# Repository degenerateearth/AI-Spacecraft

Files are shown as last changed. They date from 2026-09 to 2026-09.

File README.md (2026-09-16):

# DEGEN-1
## 1U CubeSat preliminary engineering design — Revision A

Issued 14 September 2026. Status: **AUDITABLE PRELIMINARY DESIGN / NOT RELEASED FOR FABRICATION OR FLIGHT**.

The current goal is an [education-grade, theoretically buildable design](review/Theoretical_Buildability_Standard.md).
It requires exact verifiable parts, released custom designs, reconciled interfaces
and reproducible engineering analyses. Purchasing and physical testing are later
validation stages and are not required to complete the theoretical design.

## First engineering step

The controlling first engineering gate is [Phase 1 component evidence
closure](review/First_Engineering_Gate.md). DEGENERATE-1 must establish an exact,
commercially obtainable or explicitly custom-designed component for every
required function before further simulation, higher-fidelity CAD, procurement or
performance claims can control the project. Existing calculations and CAD remain
preliminary records and do not supply missing component properties.

The [Phase 1 closure review package](Components/phase1_closure/README.md) now
supersedes the earlier 29-line operating proposal for review. Its consolidated
register contains 52 flight, ground and support records: 5 bounded component-level
SUPPORTED records, 25 genuine custom work packages and 22 explicit COTS or
configuration evidence exceptions. No flight component is newly admitted, and
no custom work package is a released design. G1 therefore remains open.

The design targets one year of opportunistic imaging and housekeeping telemetry in LEO at low build cost using commercially marketed CubeSat subsystems. The owner selected occasional recognizable Earth images, US operation and nominal 450–500 km LEO, with no arbitrary spacecraft budget ceiling. Revision A proposed a CrystalSpace CS-101 camera; the evidence audit prefers SkyFox piCAM/FM, but neither is admitted to the Phase 1 baseline. Selected-location imaging or mapping would require a revised baseline.

The original pre-gate candidate architecture used an ISISPACE 1U chassis,
ICEPS2 power, and GomSpace avionics. The [open-bus architecture
trade](engineering/12_Open_Bus_Architecture_Trade.md) now rejects that mixed
commercial set as the design-development baseline because necessary public
interfaces do not close. Degen-1 will develop a BIRDS-derived 1U architecture
with project-released custom avionics and current exact BOMs. This is an
architecture direction, not an admitted component baseline; G1 remains open.

The original [component audit](Components/README.md) covers every existing B01–B16 BOM line. The stricter [Phase 1 functional audit](Components/Phase1_Functional_Audit.md), [105-row property matrix](Components/Phase1_Component_Property_Matrix.csv) and [evidence standard](review/Phase1_Component_Evidence_Standard.md) find that **no physical component has yet passed into the Phase 1 baseline**. Named products remain candidates until public primary evidence establishes every mission-relevant property. The audit identifies SkyFox `piCAM/FM` as a better documented camera candidate, corrects NanoDock DMC-3 availability, and records Pumpkin structure/panel alternatives without promoting them. None of these findings silently changes the controlled BOM.

**Planning results:** 1.064 kg current best estimate, 1.276 kg including 20% growth; EUR46,500 base flight-hardware allowance (EUR29,350–70,100 range). These are engineering estimates, not supplier quotations. Spacecraft build, including engineering/prototype hardware, assembly and nonrecurring engineering labor, is EUR152,500 base before contingency. Testing, ground station, licensing, launch and operations are separate categories. The cost report explains inclusions and uncertainty.

The original scalar power model closes nominal energy at +18.4% with a tumble-average assumption and reported +0.124 Wh/orbit for fixed-attitude recovery. The later 11-node calculation is reclassified as **HYPOTHETICAL PARAMETRIC SENSITIVITY — NOT COMPONENT-SPECIFIC** after the [Thermal Model Incident](review/incidents/Thermal_Model_Incident.md). Its precise numerical outputs depend on unsupported thermal properties and cannot pass or fail the spacecraft or an identified component. Thermal feasibility, orbit lifetime, radiation, inhibit independence and final mechanical/interface compliance remain open. No analysis in this package demonstrates launch survival or twelve-month operation.

### Audit reading order

1. [First engineering gate](review/First_Engineering_Gate.md), [Phase 1 evidence standard](review/Phase1_Component_Evidence_Standard.md), and [functional component audit](Components/Phase1_Functional_Audit.md)
2. [Mission and architecture](engineering/01_Mission_and_Architecture.md)
3. [System budgets and analysis rationale](engineering/02_Budgets_and_Analyses.md)
4. [Interfaces and adapter specification](engineering/03_Interfaces.md)
5. [Mechanical and environmental design](engineering/04_Mechanical_Thermal_Radiation.md)
6. [Flight software and mission operations](engineering/05_Software_and_Operations.md)
7. [Assembly, integration and verification](engineering/06_Integration_and_Verification.md)
8. [Cost and procurement trade](procurement/Cost_and_Procurement.md)
9. [Open issues and review gates](review/Open_Issues.md)
10. [Imaging payload](engineering/07_Imaging_Payload.md) and [US compliance plan](engineering/08_US_Compliance.md)
11. [Launch and deployer planning baseline](engineering/09_Launch_and_Deployer_Baseline.md)
12. [Preliminary transient thermal-power analysis](engineering/11_Transient_Thermal_Power_Analysis.md)
13. [Requirements traceability](review/Requirements.md), [FMEA](review/FMEA.md), [sources](review/Source_Register.md)
14. [Known downstream dependencies](review/Known_Downstream_Dependencies.md)
15. [Phase 1 consolidated component register](Components/phase1_closure/component_register.md), [alternatives](Components/phase1_closure/alternative_review.md), and [build-and-operate completeness audit](Components/phase1_closure/completeness_audit.md)
16. [Open-bus architecture trade](engineering/12_Open_Bus_Architecture_Trade.md) and [upstream revision register](review/Open_Source_Upstream_Register.md)

### Reproduction and configuration

Run `python analysis/recalculate.py` for the original scalar budgets. Run `python analysis/thermal_transient.py --self-test` for the 11-node transient thermal-power model; its canonical inputs are `analysis/thermal_inputs.json` and its CSV/JSON/SVG outputs are regenerated. Both scripts use Python's standard library. Assertions and numerical checks verify model consistency, not flight hardware. The HTML audit book is an earlier generated snapshot; the individual Markdown documents and model inputs are authoritative within this package.

The original SVG is an allocation sketch. [CAD-001 FreeCAD model](drawings/freecad/README.md) now provides editable parametric component envelopes and a STEP review export, with explicit assumptions and fit conflicts. It is not manufacturing CAD or supplier geometry. The electrical diagrams specify functional interfaces, not a released pin-to-pin harness. PCB fabrication files, vendor proprietary ICDs, supplier quotes, hardware test reports and flight software implementation remain incomplete.

All external facts carry source IDs resolved in the source register. **V** denotes vendor-stated information; **A** denotes an engineering assumption/allocation; **C** denotes a calculation; **OPEN** denotes missing evidence. Published product changes supersede older brochures. Engineering approval signatures remain blank; AI authorship is not an engineering release.

## Project purpose — added after Revision A

Read the [Project Overview](Project_Overview.md) for the AI-assisted engineering experiment and the owner's [Project Constitution v0.1](Project_Constitution.md) for its principles and success levels. The Revision A audit book remains the earlier technical snapshot; these documents do not imply a new engineering or flight-readiness release.
## Consumer-AI experiment constraint

The baseline engineering interface is a standard $20/month ChatGPT Plus subscription, including Codex/Astra where available, with free/open-source engineering tools wherever practical. Paid AI or software is not introduced silently. See [AI toolchain and boundaries](review/AI_Toolchain_and_Boundaries.md), [project status](review/Project_Status.yaml), and the separate [project cost ledger](procurement/Project_Cost_Ledger.csv).

Project gates and their required evidence are tracked in [MILESTONES.md](MILESTONES.md). GitHub updates are made at those review points.

Before planning major engineering work, consult the [Master CubeSat Readiness Checklist](review/Master_CubeSat_Readiness_Checklist.md). It audits this repository against an independent University of Hawaiʻi CubeSat development framework plus primary launch, NASA and US regulatory sources. The public-information-phase reassessment leaves the project at Constitution Level 0 with partial evidence toward Level 1. It distinguishes current work from final closure that depends on later vendor, regulator, integrator, test or expert evidence.

The [Launch and Deployer Constraint Gate](engineering/09_Launch_and_Deployer_Baseline.md) selects a standard 1U EXOpod Nova slot as a provisional mechanical reference. No launch, orbit, price, mission ICD or acceptance is selected. EXOLAUNCH and ISISPACE require written offers; ISS/NRCSD remains a lower-orbit fallback whose one-year residence is unproved.

The project is presently in a public-information development phase. Direct
contact for private or mission-specific evidence is tracked as a [known
downstream dependency](review/Known_Downstream_Dependencies.md), while public
analysis, CAD, simulation and test planning continue. This sequencing does not
waive public requirements or turn provisional inputs into release evidence.

Archived external-framework provenance and licensing are recorded in [SOURCES/README.md](SOURCES/README.md).

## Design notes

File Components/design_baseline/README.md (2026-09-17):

# Degen-1 detailed-design selection register

Revision A · 2026-09-16

This directory records exact parts and custom assemblies selected after
D1-TRD-ARCH-001. A selection here is an input to detailed design. It becomes
`SUPPORTED` under D1-CMP-STD-001 only when every property actually used by the
released design is backed by primary evidence.

Current states:

| State | Meaning |
|---|---|
| SELECTED FOR DETAILED DESIGN | Exact part/topology chosen; further interface, circuit or analysis closure is required |
| SUPPORTED | Exact selection and all controlling mission properties are evidenced for the stated use |
| CUSTOM/TO BE VERIFIED | Degen-1 design has a defined identity and verification path; release artifacts are incomplete |
| REJECTED | Evaluated and unsuitable for the baseline, with reason retained |

| ID | Item | State | Record |
|---|---|---|---|
| D1-BAT-001 | 3S2P Panasonic BK120AAHU battery assembly | SELECTED FOR DETAILED DESIGN | [Battery record](D1-BAT-001.md) |
| D1-OBC-001 | BIRDS-derived PIC/serial-flash OBC | CUSTOM/TO BE VERIFIED | [OBC record](D1-OBC-001.md) |
| D1-EPS-001 | Power, charging, rails and launch inhibits | CUSTOM/TO BE VERIFIED | [EPS record](D1-EPS-001.md) |
| D1-BPB-001 | Backplane and fixed electrical interfaces | CUSTOM/TO BE VERIFIED | [Backplane record](D1-BPB-001.md) |
| D1-CAM-001 | SkyFox Labs piCAM/FM camera and custom carrier | SELECTED FOR DETAILED DESIGN | [Camera record](D1-CAM-001.md) |
| D1-COM-001 | Ebyte E22-400M22S UHF radio and custom carrier | CUSTOM/TO BE VERIFIED | [Radio record](D1-COM-001.md) |
| D1-SOL-001 | Five custom panels with ten AZUR SPACE 81442 SCAs and five YAGEO Nexensos 32208571 Pt1000 sensors | CUSTOM/TO BE VERIFIED | [Solar-panel record](D1-SOL-001.md) |
| D1-ADCS-001 | K&J D84 magnet, two custom HyMu 80 rods and retainers | CUSTOM/TO BE VERIFIED | [Passive ADCS record](D1-ADCS-001.md) |
| D1-ANT-001 | Custom 436.5 MHz canted-turnstile and four-channel release assembly | CUSTOM/TO BE VERIFIED | [Antenna/deployment record](D1-ANT-001.md) |
| D1-STR-001 | BIRDS-4-derived custom 1U rail frame | CUSTOM/TO BE VERIFIED | [Structure record](D1-STR-001.md) |
| D1-FAB-001 | Launch inhibits, RBF and front service access | CUSTOM/TO BE VERIFIED | [Flight-access record](D1-FAB-001.md) |
| D1-HAR-001 | Flight and removable service harnesses | CUSTOM/TO BE VERIFIED | [Harness record](D1-HAR-001.md) |

This register will replace the earlier mixed-vendor component proposal only
after all required functions have equivalent detailed records and the generated
Phase 1 register is revised. Until then, the earlier register remains the formal
list of open evidence exceptions and G1 remains open.

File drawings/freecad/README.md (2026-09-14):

# Degen-1 CAD-001 — FreeCAD accommodation model

MODELED / PRELIMINARY / NOT FOR FABRICATION OR FLIGHT.

This translates the existing Revision A spacecraft into editable component
envelopes. It does not substitute a generic 1U design. Read
[TRACEABILITY.md](TRACEABILITY.md) and [FINDINGS.md](FINDINGS.md) before using it.

- `parameters.json`: canonical dimensional inputs, object names, evidence, sources and requirements.
- `build.py`: canonical generator, intersection audit, assigned BOM masses and verification routine.
- `Build_Degen1.FCMacro`: run in the installed FreeCAD GUI to regenerate and preview.
- `exports/Degen1_CAD001.FCStd`: editable native document with Spreadsheet-driven Part boxes.
- `exports/Degen1_CAD001_envelopes.step`: interoperability solids; references and unknown interfaces excluded. All solids are bounding/allocation volumes, not material.
- `exports/assembly.png`: FreeCAD view, when generated by GUI macro.
- `exports/geometry_report.json`: computed overlaps, distances, bounds and mass reconciliation.
- `exports/verification.json`: saved-file and STEP software verification.

## Reproduction

Installed tool: FreeCAD 1.1.3, revision 20260725, Python 3.11 (bundled).
No paid tools, cloud compute or external engineering service used for this CAD work.

In FreeCAD, open the macro through Macro > Macros and Execute. It resolves paths
relative to itself. It creates a new document, retaining any other open document.
Close unsaved variants deliberately yourself; do not confuse them with the saved baseline.

For repeatable command-line generation using this computer's installed FreeCAD:

```powershell
& "$env:LOCALAPPDATA\Programs\FreeCAD 1.1\bin\python.exe" "D:\Degen-1\drawings\freecad\build.py"
& "$env:LOCALAPPDATA\Programs\FreeCAD 1.1\bin\python.exe" "D:\Degen-1\drawings\freecad\build.py" --verify
```

The commands use the actual installed FreeCAD modeling kernel. The GUI macro
also saves colors, transparency and a view. Headless regeneration preserves
geometry but does not produce the same graphical presentation.

Edit the native `Parameters` spreadsheet's B column and recompute to change
dimensions/centers. All boxes have expression-driven size and location.
For durable reproducibility, propagate accepted edits back to `parameters.json`
and regenerate; generation overwrites the saved output files. STEP cannot retain
the expression graph, evidence metadata or unknown-interface records.

`References` contains hidden nominal envelope, bay and service-clearance volumes.
Toggle their visibility for inspection; they are not physical parts or masses.
`UnresolvedInterfaces` contains records without geometry so missing hardware is
visible in the tree. Turn off `SolarPanels` for an internal view.

Geometry checks enumerate every component pair, calculate Boolean intersection
volumes, report distances <=3 mm, and check containment in the project nominal
100 x 100 x 113.5 mm envelope. 3 mm is a reporting threshold, not a requirement.
No universal clearance acceptance, tolerance analysis, mounting validation,
structural simulation, thermal simulation or hardware test is implied.

Verify regenerations by comparing geometry signatures, not FCStd/STEP binary
hashes: files may contain time-dependent metadata. Verification reopens FCStd in
a fresh process, changes camera length through its spreadsheet expression,
restores it, checks all solids and reads STEP back. Expected overlaps are retained.

GitHub milestone identifiers M0-M7 are organizational checkpoints, distinct from
constitution success levels. This first CAD does not close M2/M3 or increase the
existing success-level claim.

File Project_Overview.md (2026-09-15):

# DEGENERATE-1 — Project Overview

Version 0.1 · Living document · 14 September 2026

## What this project is

DEGENERATE-1 is an experiment in how far a non-engineer can get in spacecraft engineering and development using AI as their primary tool.

The project follows a real spacecraft-development effort and documents what AI helps accomplish, what it gets wrong, what the human operator learns, and where independent expertise or physical testing becomes necessary. Its value comes from a credible, inspectable record of progress, including any limits that prevent it from reaching orbit.

AI is the main interface for research, calculations, design exploration, software and documentation. It is not an engineering authority. A convincing answer or a polished document is a proposal to examine, not proof that a spacecraft will work.

## The spacecraft mission

The practical objective is to build a small spacecraft that captures a recognizable photograph of Earth, stores it onboard, transmits it to a privately constructed ground station, and allows that station to reconstruct the image. Basic telemetry should show whether the spacecraft is healthy.

The memorable finish line is a physical printer at the ground station producing the photograph received from orbit: the constitution's **Cornfield Criterion**.

High-resolution mapping, selected-location targeting and real-time video are unnecessary for this objective. The owner has selected occasional recognizable Earth images.

## What the experiment should measure

Progress should be measured by evidence and demonstrated capability. For each meaningful milestone, record:

- What the non-engineer asked AI to help accomplish.
- What AI proposed, including its assumptions and sources.
- What calculations, source checks, independent review or tests supported or contradicted the proposal.
- What changed, why it changed, and who identified the problem.
- How much human effort, specialist assistance, money and time were required, when known.
- What the human operator can now explain or demonstrate.

These records should make it possible to distinguish AI-assisted progress from work completed by suppliers, professional engineers or test facilities. Both are useful contributions; their roles should remain visible.

This is a documented case study. One project's outcome will not establish that AI can replace aerospace engineers generally.

## What counts as success

The constitution defines separate stages: concept, supported engineering model, expert review, ground prototype, verified flight-candidate hardware, licensed launch readiness, orbital operation, image return and finally the printed photograph.

Reaching one stage does not establish the next. A useful result could also be a well-documented stopping point: for example, discovering that a required interface cannot be verified, a design lacks sufficient margin, or the cost of qualification makes the mission impractical.

Meaningful failures belong in the record. Preserve the original proposal, the problem discovered, the correction and the lesson. Correct the current design without rewriting the history of how it arrived there.

## Current starting point

The existing **Degen-1 Revision A** package is a preliminary 1U CubeSat design for opportunistic Earth imaging. It includes component candidates, calculation files, estimated costs, requirements and open issues.

It provides a concept and partial evidence toward the constitution's engineering-model stage. It does not establish a fully consistent, verified engineering model or any higher success level. No independent expert review, hardware purchase, prototype, environmental qualification, licensing approval or orbital operation has been demonstrated in the project record so far.

The initial technical baseline targets US operation in approximately 450–500 km LEO and twelve months of operation. The constitution allows a different form factor when a documented trade supports it. It also defines the minimum image-return objective separately from the original twelve-month target. This overview does not silently remove that target or change the current hardware architecture; any such change should be an explicit, traceable design decision.

## How the project should develop

The first engineering step is to close the Phase 1 component evidence gate. The
project must identify an exact documented COTS configuration or release a custom
design for every required function before additional simulation or detailed CAD
can become the controlling work product. Preliminary work already present in the
repository remains useful for discovering required properties and conflicts, but
it does not reverse this order or establish component behavior.

Prefer designs that can be understood, sourced, checked, built and tested. Use commercially available hardware where it reduces total effort and risk. Keep assumptions and missing information visible, propagate design changes through all affected budgets, and obtain appropriate specialist review before treating work as independently validated.

Explain important decisions in language the operator can understand: the decision, its purpose, the evidence, the assumptions and how it could be verified. Developing the operator's understanding is part of the experiment.

The intended public record should show both the spacecraft's development and AI's actual contribution. GitHub is the intended canonical technical record; a future website should explain the project and link to that record. No repository or publication is created by this document. Files currently remain in `D:\Degen-1`.

## Project documents

- [Project Constitution v0.1](Project_Constitution.md) — the owner's full statement of purpose and working principles, preserved as supplied.
- [Technical package README](README.md) — entry point to the existing design documents and calculations.
- [Revision A audit book](Degen-1_Audit_Book.html) — the earlier technical snapshot; it predates this overview and constitution.
- [Open issues](review/Open_Issues.md) — unresolved technical and regulatory evidence.

**North star:** a spacecraft we built photographs Earth, sends the image home, and our ground station prints it—while leaving an honest record of how far AI helped us get.
## Consumer-AI boundary

The accessibility baseline is a standard $20/month ChatGPT Plus subscription, including Codex/Astra where available, plus free and open-source engineering software wherever reasonably practical. Enterprise AI, specialist AI platforms, large API expenditures, paid cloud compute and paid engineering services are not silently added. If the consumer/free toolchain reaches a credible boundary, record the limitation, required capability and estimated cost and ask before introducing a paid tool or service.

Keep AI/tooling costs separate from spacecraft hardware, ground station, testing, licensing, launch/integration, and external human expert review. Physical testing is not AI expenditure, and professional review must be attributed to human expertise.

## Current public-information phase

The current phase deliberately uses public standards, manuals, datasheets,
research and free/open tools to mature the design as far as they credibly allow.
External requests for private or mission-specific information are deferred until
they are needed for an irreversible or expensive commitment. Those needs are
tracked as **KNOWN DOWNSTREAM DEPENDENCIES**, together with the useful analysis,
CAD, simulation and prototype work that can continue now.

This sequencing does not convert provisional public information into an
approved interface. The public EXOpod Nova manual remains the provisional
mechanical reference. A current mission ICD, as-procured component data,
regulatory determinations, physical test evidence and professional review will
still be required at their applicable release gates.

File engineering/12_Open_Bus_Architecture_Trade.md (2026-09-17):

# D1-TRD-ARCH-001 — Open-bus architecture trade

Revision A · 2026-09-16  
Evidence state: **DOCUMENTED TRADE STUDY; no hardware tested**

## Decision question

Which publicly documented architecture provides the most credible path to a
complete, auditable, education-grade 1U Earth-imaging design without depending
on private vendor interfaces?

The comparison is about the public design record. Flight heritage of a related
revision is supporting evidence, not proof that a Degen-1 derivative will work.

## Mandatory criteria

1. A 1U implementation must be physically possible.
2. Hardware must be represented by exact COTS parts or released custom designs.
3. Schematics, PCB source or a declared custom-layout task, mechanical interfaces,
   firmware and test information must be publicly reviewable.
4. The design must support command, health telemetry, image capture, storage and
   image downlink without a hidden command protocol.
5. Known radiation, power, safety or integration failures must remain visible.
6. The editable toolchain must be free/open where reasonably practical.

## Results

| Candidate | Public strengths | Controlling defects | Disposition |
|---|---|---|---|
| Existing ISISPACE/GomSpace/SkyFox mix | Current identifiable products; compact flight-oriented packaging | Several command definitions, option codes, pinouts and cross-vendor configuration details are not public; 22 evidence-incomplete selections remain in the Phase 1 register | Rejected as the design-development baseline; retained as a commercial comparison |
| BIRDS-4/BIRDS-5 1U bus | Repeated 1U educational missions; English platform ICD; structure CAD; board schematics and BOMs; firmware; antenna, battery and environmental procedures; documented energy figures; direct Earth-imaging precedent | Core OBC/EPS PCB layouts are not public; some 2018 BOM entries are obsolete or ambiguous; the exact current radio configuration and procurement route require reconciliation | **Selected reference architecture for a Degen-1 custom derivative** |
| PyCubed v05 | Complete KiCad source, fabrication data, STEP, firmware and integrated OBC/EPS/radio | The project warns of serious proton sensitivity in the ATSAMD51 used by v00–v05; example command handling includes static tokens and unrestricted evaluation/execution; solar-input topology conflicts with ordinary two-cell 1U body panels | Rejected unchanged; retained as an implementation reference |
| OreSat0 / OreSat current repositories | Coherent open card-cage architecture; 1U flight article; open C3, backplane, battery and solar designs; strong fabrication notes and test culture | Flown C3 v5 had both receiver defects; current C3 v6 is a post-flight redesign with no public board power characterization found; flown battery v3.0 is an older Eagle design while current KiCad layout is explicitly in progress | Strong reference, not a single reproducible current baseline |
| VST104-Sierra | Complete KiCad OBC, exact BOM alternatives, broad protected interfaces and STM32L496 firmware scaffold | No mission flight software; needs both 3.3 V and 5 V; no matched EPS/radio in the VST104 set; no flight or radiation-test record found | Retained as OBC fallback/reference |
| OpenLST rev 2.1 | Complete KiCad, Gerbers, exact BOM, firmware, ground tools and extensive related Planet LST flight heritage | Reference PA RFFM6403 is discontinued; STA1120A evidence/order route is incomplete; board connector selections are unfinished; a current derivative requires RF redesign and test | Retained as radio fallback/reference |
| UPSat open bus | Flown fully open satellite with EPS, OBC, communications, camera software, structures and verification history | The integrated spacecraft is 2U; 2016 parts/tooling need obsolescence review; a 1U repack would be a new mechanical and thermal design | Retained as subsystem and verification reference |

## Selected architecture direction

Degen-1 will use a **BIRDS-derived 1U mechanical and electrical architecture with
project-released custom avionics boards**. The selection is architectural, not an
authorization to copy an unavailable board layout or to treat old BOM entries as
current.

The reasons are:

- BIRDS demonstrates that the chosen stack style, passive-stability concept,
  body-mounted solar generation, low-data-rate UHF link and small camera payload
  can coexist in 1U;
- the public platform ICD, circuit schematics, firmware and verification records
  expose more of the complete spacecraft than the commercial mixed-vendor design;
- Degen-1 can recreate the missing layouts in KiCad and record every substitution,
  instead of relying on private command dictionaries; and
- the architecture already separates platform, communication, antenna, payload
  and backplane functions in a form that can be audited by students and engineers.

## Frozen functional partition

| Degen-1 item | Baseline direction | Present evidence state |
|---|---|---|
| Structure and rails | Custom D1-STR-001 derived from public BIRDS 1U drawings and checked against the provisional EXOpod Nova envelope | Selected direction; Degen-1 production drawings not released |
| Backplane and harness | Custom D1-BPB-001 using the BIRDS 50-pin stack interface as the starting pin map | Selected direction; pin-level Degen-1 ICD not released |
| OBC and nonvolatile storage | Custom D1-OBC-001 derived from the BIRDS-4 PIC/flash architecture and firmware; every obsolete/ambiguous part must be replaced before schematic release | Selected direction; layout and current BOM not released |
| Power, inhibits and distribution | Custom D1-EPS-001 derived from the BIRDS FAB/EPS safety architecture, with three independent deployment inhibits, RBF isolation, battery protection and separately switched payload/radio rails | Selected direction; schematic and current BOM not released |
| Battery | Custom D1-BAT-001 using six exact Panasonic `BK120AAHU` NiMH cells in a 3S2P topology | Exact cell and topology selected; pack drawing, analysis and verification remain open |
| Solar panels | Custom D1-SOL-001 body panels using exact AZUR `81442` SCAs, Nexperia blocking diodes and YAGEO Nexensos `32208571` Pt1000 sensors; PCB, readout and attachment remain to be released | Open detailed design |
| TT&C and image downlink | Custom D1-COM-001 carrier using exact Ebyte `E22-400M22S` / Semtech SX1268 module; public Degen-1 waveform and packet protocol | Exact module selected; carrier, waveform and link closure open |
| Antenna/deployment | Custom D1-ANT-001 derived from the documented BIRDS tape-antenna mechanism and launch-inhibit logic | Selected direction; drawings and release circuit not released |
| Camera | SkyFox Labs `piCAM/FM`, default approximately 60-degree optics, IR-cut and infinity focus | Exact payload selected; carrier, delivered connector suffix and protection release open |
| Passive attitude behavior | Permanent magnet plus hysteresis material only if exact sizing and image-probability analysis close; no active pointing is added | Open detailed design |
| Flight software | Degen-1 fork/reimplementation of the BIRDS state-machine and command concepts with authenticated command parsing, bounded buffers and no dynamic evaluation | Custom work package |
| Ground segment | SDR/packet modem, directional antenna, rotator and image reconstruction matched to the released space link | Custom integration plus exact COTS items |

## Design boundary exposed by the trade

No reviewed open design simultaneously provides a current exact BOM, complete
1U fabrication package, demonstrated 12-month radiation tolerance, camera mission,
and fully documented ground link. Degen-1 must perform real electrical, RF,
mechanical and software design work. Reusing public source reduces the amount of
new work; it does not transfer qualification or flight status.

The consumer-AI/free-toolchain experiment can credibly continue through source
reconciliation, KiCad/FreeCAD design, deterministic analysis and prototype test
planning. RF layout review, battery safety review, launch structural review,
environmental qualification and regulatory approval remain expected external or
physical-verification boundaries.

## Primary public records used

- BIRDS platform documentation: https://github.com/BIRDSOpenSource/BIRDS-GeneralDocumentation
- BIRDS-4 OBC: https://github.com/BIRDSOpenSource/BIRDS4-OBC
- BIRDS-4 communications: https://github.com/BIRDSOpenSource/BIRDS4-COM
- BIRDS-4 FAB/EPS: https://github.com/BIRDSOpenSource/BIRDS4-FAB
- BIRDS-4 CAD and procedures: https://github.com/BIRDSOpenSource/BIRDS4-CAD and https://github.com/BIRDSOpenSource/BIRDS4-ProceduresAndReports
- BIRDS-5 published parts/designs/CAD/source: https://github.com/BIRDSOpenSource
- BIRDS-RPM communication record: https://birds-rp.birds-project.com/communication/
- PyCubed hardware/software: https://github.com/pycubed and the August 2024 processor notice in its official documentation
- OreSat hardware: https://github.com/oresat/oresat-c3-hardware, https://github.com/oresat/oresat-batteries, https://github.com/oresat/oresat-solar-hardware, and https://github.com/oresat/oresat-backplane
- VST104-Sierra: https://github.com/visionspacetec/VST104-Sierra
- OpenLST: https://github.com/OpenLST/openlst and https://www.planet.com/open/openlst-hw.git
- UPSat: https://gitlab.com/librespacefoundation/upsat

Exact upstream commit identifiers used for this audit are recorded in
`review/Open_Source_Upstream_Register.md`.

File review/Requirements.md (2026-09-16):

# D1-REQ-001 — Requirements and verification traceability

Revision A. A=analysis, T=test, I=inspection. MODEL PASS is not hardware compliance. Tests resolve to D1-AIV-001; all executed work here is document/model verification only.

| ID | Requirement | Origin | Owner | Method | Evidence | Status |
|---|---|---|---|---|---|---|
| R01 | Operate for 365.25 days after separation | User | System | A/T | T07,T08,T13,T16,T17 | OPEN: life evidence |
| R02 | Return occasional recognizable Earth images; commissioning image and monthly target | User + allocation | Payload | A/T | T11,T17 | OPEN: opportunity and image test |
| R03 | Use standard 1U rail-deployer envelope; EXOpod Nova is provisional mechanical reference and final ICD governs | User/S01/S33 | Mechanical | I/T | T01 | PROVISIONAL MODEL SCREEN: nominal 100 x 100 x 113.5 mm; tolerances and fit open |
| R04 | Mass <=1330 g project target; actual manifest limit governs | Allocation/S33 | Mechanical | A/T | T02 | MODEL PASS:1276.2 g with growth versus 2.5 kg public Nova reference; hardware/manifest open |
| R05 | COM target +/-10mm in each axis | Allocation/S33 | Mechanical | T | T02 | OPEN: project target is tighter than Nova +/-20 mm guidance; credible model and measurement absent |
| R06 | Minimum-cost viable theoretical design; maximize practical use of documented COTS hardware and define every necessary custom item | User | Systems | Review | Cost model and design register | OPEN: detailed baseline and estimates |
| R07 | Nominal orbit-energy balance positive after 20% growth | Allocation | EPS | A/T | T06,T07 | MODEL PASS:+18.4%; environment inputs open |
| R08 | Recovery energy closes in worst intact-face attitude, camera off | Allocation | EPS/FSW | A/T | T06,T07,T13 | OPEN: scalar screen is assumption-dependent; hypothetical thermal study is not component evidence |
| R09 | Battery routine DOD <=20% EOL capacity; >=6000-cycle evidence | Allocation | EPS | A/T | T08 | MODEL PASS DOD only; life open |
| R10 | Never charge outside approved cell current/temperature limits | S03/project target | EPS | T | T03,T13,T15 | OPEN: public product limits are partial; exact delivered configuration, independent control and physical tests remain open |
| R11 | Three independent physical RF and release inhibits unless approved tailoring | S01/S39; mission ICD TBD | Safety | A/T | T04 | OPEN: public Nova manual does not close circuit independence or mission safety acceptance |
| R12 | No early deployment/RF; delays >=30/45min or longer ICD | S01 | Safety/FSW | T | T05 | OPEN |
| R13 | RBF/source isolation includes solar and service paths | S01/S03 | Safety | A/T | T04 | OPEN |
| R14 | Recover from OBC hang, bus fault and low battery autonomously | Allocation | FSW/EPS | T | T07,T15 | OPEN |
| R15 | No downstream overvoltage or back-powering at avionics | S03/S08/S10 | Electrical | A/T | T03 | OPEN: adapter design |
| R16 | Correct Mode 5 framing with >=3dB tested link reserve | S11/allocation | RF | A/T | T09 | MODEL PASS:6.49dB down; threshold open |
| R17 | RF band, EIRP and sites authorized before use | User | Regulatory | Review | FCC/coordination grants | OPEN |
| R18 | NOAA determination/license for full imaging capability | User/S24 | Regulatory | Review | NOAA evidence | OPEN |
| R19 | Retain 30 days health and bounded image store | Allocation | FSW | T | T11,T15 | OPEN |
| R20 | Authenticated critical commands, replay control and persistent RF stop | Allocation | FSW | T | T15,T17 | OPEN: license-compatible implementation |
| R21 | Structure survives approved launch environment | User | Mechanical | A/T | T12,T18 | OPEN: analysis and test |
| R22 | Thermal model closes charging/survival and energy simultaneously | User | Thermal | A/T | T13 | NOT STARTED: the existing calculation is hypothetical sensitivity only; critical component properties and correlation are absent |
| R23 | One-year radiation/SEE assurance covers every critical revision | User | EEE | A/T | T16 | OPEN |
| R24 | No unintended debris; materials/venting meet ICD | User/S01 | Mechanical | I/A | T01,T12 | OPEN |
| R25 | Orbit lasts mission and disposes within applicable deadline | User/S16 | Mission | A | Decay/demise analysis | OPEN |
| R26 | End-of-mission power sources safely passivated | User | EPS/ops | A/T | T17 | OPEN: supplier capability |
| R27 | Camera aperture retains >=1.8W guaranteed panel output | Allocation | Payload/EPS | A/T | T06 | OPEN: vendor geometry |
| R28 | Camera exposure/optics survives uncontrolled Sun views and environment | Allocation | Payload | A/T | T11,T13,T18 | OPEN |
| R29 | Camera <=2W peak and <=300s/day; processing within 0.02W average allocation | Allocation | Payload/FSW | T | T07,T11 | OPEN: vendor brief |
| R30 | Fit and function unaffected after environmental tests | User | AIV | T | T01,T18 | OPEN |
| R31 | Maintain traceable hardware/software/material configuration and raw test data | Audit requirement | QA | Review | Build records | OPEN |
| R32 | Separate build, testing, launch, licensing and ground costs | User | Cost | Review | Program_Cost.csv | DOCUMENTED; estimates only |
| R33 | Trackability, conjunction contacts and operating procedures ready | User | Ops | Review | T17/analyses | OPEN |
| R34 | Each supplier replacement reopens affected budgets and evidence | Allocation | QA | Review | Change control | DEFINED; process implementation open |
| R35 | Close Phase 1 component evidence for every required function before further simulation or high-fidelity CAD controls the project | User | Systems | Review | D1-GATE-001 | OPEN: 0 components admitted |

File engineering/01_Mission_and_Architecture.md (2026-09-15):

# D1-SYS-001 — Mission and architecture

**Phase 1 component status, 2026-09-15:** This document describes a candidate
architecture. Under D1-CMP-STD-001, no physical component is yet admitted to the
Phase 1 baseline. Product names below are allocations for audit, interface work
or trade study; `procurement/BOM.csv` and the component property matrix carry the
current evidence status.

Revision A | 2026-09-14 | Preliminary

## Mission definition

Demonstrate low-cost opportunistic Earth imaging and spacecraft health monitoring for 365.25 days after separation. Image requirement: return at least one recognizable Earth image during commissioning and target one useful image per month thereafter, including the final mission month. This image cadence is an allocated target, not a demonstrated coverage result. Success is at least one authenticated command and one valid health dataset during each rolling seven-day interval after commissioning, including an interval at mission day 365. The weekly criterion accommodates outages; it is not a promise of continuous ground coverage. Nominal target: daily telemetry retrieval. Minimum useful dataset: battery voltage/current/temperature, solar input power, resets, mode, uptime and radio temperature. Inertial data use sensors already on the OBC and are secondary.

Assume a US private operator, a single spacecraft and no commercial communications service. US operation and low build cost are owner requirements. Noncommercial demonstration is the provisional operating model; radio-service eligibility is not yet determined. Planning orbit: circular 475 km, inclination 51.6 degrees; trade range 450–500 km. Epoch, inclination, RAAN, injection dispersions, ground location and launch provider remain unselected. Higher-inclination rideshares require new radiation, thermal, contact and lifetime analyses. Do not buy an RF variant before the radio-service decision.

Functional operation for a year and remaining in orbit for a year are separate requirements. A lower orbit may decay too early; a higher orbit may not dispose quickly enough. No propulsion is provided. The launch orbit must pass both gates using appropriate atmospheric uncertainty cases.

## Architecture and cost choices

The expensive items are purchased flight-oriented subsystems whose testing/documentation can reduce development effort. Ordinary commercial components are confined mainly to the interconnect/regulator adapter and ground support. A catalog product's heritage is evidence to investigate, not proof of the delivered revision's qualification.

Six photovoltaic faces remove the geometric zero-power orientation of a five-face design. Opposite faces feed three MPPT inputs through vendor-approved isolation, one axis per input. Two cells in series on each face give a nominal planning MPP voltage around 5.4 V [S04]; no opposite faces are placed in series. Cold open-circuit voltage, hot MPP voltage, shadowing and startup behavior require vendor curves. Five faces use a 2.3 W allocation; the +X camera-aperture face uses 1.8 W. The 2.3 W/face allocation is conservative relative to two current catalog cells but remains an RFQ acceptance target [S22].

The integrated two-cell battery simplifies packaging and handling. The CPU and radio share a commercial carrier but have separate switched, regulated power branches. The radio uses CAN/CSP to the OBC; EPS and antenna commands use I2C, with branch isolation. Debug connectors cannot back-power the bus during flight integration.

A 5 V AntS variant provides a deployment interface independently switched from avionics. It carries the +Z panel using the supported accommodation [S05]. A UHF turnstile is selected for broad coverage; actual pattern nulls remain. It is tuned on the assembled spacecraft. Body attitude is uncontrolled. A side-looking CrystalSpace CS-101 camera takes bursts when energy allows; the camera is disabled in recovery. No requirement relies on passive magnetic alignment, spin-axis control or a claimed detumble time. The OBC gyro characterizes rotation; excessive rotation or poor generation reduces operations.

## Functional block diagram

```text
 +/-X panels -- isolated parallel -- MPPT X --+
 +/-Y panels -- isolated parallel -- MPPT Y --+-- ICEPS2 rail / battery / safety inhibits
 +/-Z panels -- isolated parallel -- MPPT Z --+             |
                      +-----------------------------------+-------------------+
                      |                                   |                   |
               switched 5V A                       switched 5V B        switched 5V C
                      |                                   |                   |
             D1-IF regulator A                  D1-IF regulator B       AntS controller
                      |                                   |                   |
               A3200 3.3V <--------- CAN/CSP ------> AX100-U 3.3V --RF--> turnstile
                      |
               isolated I2C branches --------> EPS housekeeping / AntS control
                      |
               temperature / health / gyro telemetry
```

## Operational phases

Ground storage → integrated inhibited state → separation detection → delayed commissioning → antenna release → receive/beacon acquisition → health operations → recovery as necessary → end-of-mission passivation. Commanded RF silence must persist across watchdog resets. Lost ground contact cannot cause unrestricted high-duty transmission. A battery exhausted below the restart threshold must be able to recover from solar power without OBC intervention.

The three-inhibit provision and RBF are a supplier/launch-interface configuration requirement. A single software switch or a timer is not substituted for independent barriers. The EPS optional switch architecture is evaluated at system level with all solar and debug paths included [S03]. The design has no pyrotechnic devices, pressure vessels or propulsion. No new orbital debris is intentionally released.

## Alternative selection rule

RFQ the component baseline and a basic EXA KRATOS or Alen 1U platform simultaneously. Prefer the offer with the lowest total delivered, integrated, verified cost that meets the requirements. The present evidence supports a cost-conscious candidate, not a mathematically proven global minimum. A turnkey quote can win even if its hardware line is higher: reduced adapter design, software integration and retest effort can dominate the difference. No order or supplier message was sent.

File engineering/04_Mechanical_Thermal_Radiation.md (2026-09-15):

# D1-ENV-001 — Mechanical and environmental design

Revision A | Analysis plans plus explicit screening; qualification remains open.

## Structure and launch survival

Purchase a metal 1U flight structure and its intended rail, fastener and board-mounting system. Retain supplier materials, surface treatments and joint geometry. Flight harnesses require strain relief and positive retention. No friction-fit hobby headers, loose SD cards, consumer battery holders, adhesive-only heavy components or unapproved rework are accepted. Approved locking methods and workmanship instructions must be selected with the assembly contractor.

Rails carry dispenser interface loads into frames; board standoffs carry PCB mass into frames. Battery support must use the supplied retention system. Verify cell restraint independent of electrical terminals. Solar substrates transfer loads through approved attachment points. Antenna elements must be restrained by spacecraft hardware in the stowed state; the dispenser is not the antenna hold-down mechanism.

The rail drawing is governed by the selected dispenser ICD and CDS [S01]. Require supplier drawings, material certificates, fastener specifications, installation sequence, vent paths, mass properties and actual flight configuration CAD. Check access and serviceability with the panels and antennas installed. Outgassing evidence is required for adhesives, coatings, wire insulation and polymer components; inspect venting of every enclosed volume. Prefer already characterized material systems and minimize late finish changes.

### Preliminary load screen

For scale only, assume a 20 g quasi-static limit acceleration (A; not a launch requirement). The 1.2762 kg design mass produces 250.3 N. Uniform division over four rails is 62.6 N/rail, but real restraint preload and dynamic load sharing may be highly unequal. An EPS mass of 184 g produces 36.1 N, and with an assumed 25 mm lever arm about 0.90 N m. These are input loads, not strength margins. Use the launch coupled-loads envelope for final analysis.

Require a structural finite-element model including joint stiffness, dispenser boundary conditions, battery and daughterboard retention, panel supports, harness masses and material allowables. Extract modes, random vibration responses, stress, fastener preload/separation, buckling and fatigue where applicable. Compute `MS=allowable/(factor*applied)-1` using approved yield/ultimate factors and documented allowables. No positive structural margin or first-mode frequency is claimed without this model. A convenient 100 Hz target may guide early stiffness but is not adopted as a universal acceptance criterion.

Qualification/acceptance profiles must be agreed with the integrator. GEVS B [S15] is a tailoring reference; do not expose hardware to an arbitrary generic gRMS value. Shaker-fixture dynamics, notching, force limits and battery state matter. Components with heritage still require final assembly workmanship/acceptance testing. Current EPS and AntS webpages do not identify individual shipped-unit vibration/shock testing [S02,S05].

## Thermal architecture

Six dark solar faces offer limited radiator area. Put the battery toward the interior, provide a characterized conductive route to the structure, and use controlled isolation to prevent excessive cold coupling. Retain EPS heater sensing and add independent overtemperature protection if the provided architecture lacks the required failure protection. Place radio heat spreading to the frame; avoid coupling peak radio heat directly into the battery. Use qualified optical films only on available non-cell areas and preserve antenna/rail interfaces.

Project targets: battery +5 to +35 C during normal operation; charge only from +5 to +40 C at <=0.8 A until the vendor approves a different profile; inhibit charging below +5 C or above +40 C. Nonbattery electronics target -10 to +50 C. Deploy the antenna only from +5 to +45 C, providing margin inside the current published deployment range [S05]. These targets are allocations, not predicted temperatures. S03 distinguishes battery charge, limited-current charge and discharge ranges; the broader EPS marketing operating range is not permission to charge at subzero temperature.

### Executed screening

`thermal_screen.csv` uses a single isothermal node with radiating area 0.06 m2, effective Earth-view area 0.02 m2, and assumed projected areas 0.01–0.01732 m2. Solar flux 1322–1414 W/m2, albedo 0.20–0.35 and IR 200–260 W/m2 are illustrative bounding inputs. Optical absorptivity/emissivity are assumed, not measured. Electric power extraction is subtracted from absorbed solar heat, with internally dissipated power then added.

The equilibrium estimates are approximately -18 C for the cold sunlight case, +19 C nominal sunlight, +50 C hot sunlight and -78 C eclipse equilibrium. Eclipse equilibrium is **not** an actual 36-minute eclipse temperature; thermal inertia is absent. These results demonstrate that passive survival/charging is not closed by the current screen. They must not be used as hardware qualification predictions.

### Thermal closure method

Build at least a battery, avionics, structure and six-panel node network. Each node obeys `C_i*dT_i/dt = Q_i + sum(G_ij*(T_j-T_i)) + radiation_exchange_i`. Include battery internal resistance versus SOC/temperature, heater PWM, power conversion losses, operational modes, shadow transitions, cell extraction, varying beta and optical properties at end of life. Run cold startup after launch storage, long eclipse, repeated low-generation recovery, hot continuous-sun and high-beta cases, and heater-stuck-on/off cases. Model actual thermal conductances and uncertainties; correlate using thermal-balance testing and measured time constants.

Close the heater budget jointly with energy. The assumed 0.10 W orbit-average heater load is restrictive. If the model needs more than the available energy reserve, change thermal paths/optical surfaces or reduce operations; do not merely increase battery capacity. A larger battery does not fix a persistent negative orbit-energy balance. A 1 W heater stuck on threatens both energy and temperature and must have a bounded shutoff path.

The code in `analysis/thermal_transient.py` is retained after TMI-001 only as a
**HYPOTHETICAL PARAMETRIC SENSITIVITY — NOT COMPONENT-SPECIFIC** artifact. Its
precise output values describe an assumed mathematical network and provide no
temperature, heater-duty or energy result for ICEPS2 or the spacecraft. The
selected battery configuration, thermal interface, component heat capacities,
installed conductances, optical properties and attitude history remain unknown.
Component-specific thermal and heater-energy analysis therefore has not started.

## Radiation and other LEO exposure

Create an orbit/epoch-specific radiation environment and shielding sector model before making a twelve-month reliability claim. Run trapped particle and solar/proton/heavy-ion cases using an appropriate validated environment tool and retain all inputs/model versions. Assess total ionizing dose at the CPU, memory, EPS controller, switches, radio and adapter regulators, plus displacement damage to solar cells. Apply a preliminary radiation design margin factor 2 to the calculated mission dose when evaluating test evidence. This factor is a project allocation, not a universal standard.

Obtain part-level or assembly-relevant dose/SEE evidence tied to delivered lot/revision. Destructive latchup and power MOSFET failure cannot be fixed by a watchdog; power limiting is useful only if its response prevents damage. Memory upset recovery uses CRC, independent boot images and persistent counters, but does not provide quantified mission reliability. No arbitrary aluminum thickness is presented as sufficient shielding. NASA guidance emphasizes the application-specific nature of SEE assurance [S17].

Assess atomic oxygen/UV damage to exposed polymers, cell coverglass and adhesive edges; spacecraft charging and electrical bonding; vacuum effects on heat transfer and lubricant; and micrometeoroid/debris risk. Preserve material certificates and test evidence. This design accepts single-string critical hardware to control cost, so single-point failures remain. No numeric probability of one-year survival is claimed.

## Orbit lifetime and disposal

Use the as-built mass and projected drag area distribution, including deployed antenna influence, to propagate atmospheric decay. A rough nominal ballistic coefficient with m=1.0635 kg, Cd=2.2 and mean area=0.015 m2 is 32.2 kg/m2; plausible areas 0.01–0.01732 m2 give approximately 48.3–27.9 kg/m2. This is not a lifetime prediction.

Run launch dispersions, earliest/latest epochs, attitude cases, solar minimum and high-activity density cases. High drag must retain orbit for the operational year; low drag must meet post-mission disposal timing. Apply the applicable FCC requirements [S16] and integrator criteria, with reentry casualty/demise and collision analyses. NASA's deorbit overview [S18] supports treating this as an explicit design trade. A 475 km starting altitude is only a candidate. If no interval closes, change launch orbit or add a disposal device and re-open size, mass, cost, hazards and reliability. Do not promise passive deorbit solely from altitude.

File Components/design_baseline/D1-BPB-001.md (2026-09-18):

# D1-BPB-001 — backplane and electrical interface control

Revision C · 2026-09-18  
State: **CUSTOM/TO BE VERIFIED — connector family and logical pin allocation frozen; PCB geometry not released**

## Scope

D1-BPB-001 is the passive interconnect between the combined OBC/EPS board, radio,
camera payload, front-access/safety board and antenna-release board. It is based
on the public BIRDS 50-pin stack interface but removes the configurable CPLD
crossbar and gives every retained signal a fixed function. This reduces software,
toolchain and latent-routing complexity.

## Mechanical and connector baseline

| Item | Degen-1 selection | Evidence state |
|---|---|---|
| Backplane receptacles | Hirose `A3C-50DA-2DSA(71)`, CL0621-0524-1-71 | Current manufacturer page, drawing, STEP and specification: 50 positions, 2.0 mm pitch, 1 A/contact, -55 to +85 °C, 50.0 × 4.0 × 4.2 mm, 1.39 g |
| Mating board headers | Hirose `A3C-50P-2DSA(30)`, CL0621-0628-7-30 | Current manufacturer page, drawing, STEP and specification; identified by Hirose as mating with the selected receptacle |
| Plug-in board outline | 90 × 86 mm PCB; component-placement envelope provisionally limited to 83 × 86 mm | BIRDS Platform ICD Rev F §3.3–3.4; the text contains both dimensions and the final edge/keep-out drawing must resolve their relationship |
| Board retention | Four through holes, nominal Ø3.8 mm, for four long stack bolts | BIRDS Platform ICD Rev F §3.4; exact hole coordinates must be imported from the source drawing/CAD, not inferred from text |
| Payload thickness allocation | 22.35 mm maximum in the BIRDS reference configuration | Source-backed architectural maximum; Degen-1 stack allocation not yet closed |

Manufacturer sources:

- https://www.hirose.com/product/p/CL0621-0524-1-71
- https://www.hirose.com/en/product/p/CL0621-0628-7-30
- https://github.com/BIRDSOpenSource/BIRDS-GeneralDocumentation

The earlier BIRDS alternate `NRPN252PARN-RC` is not carried into the Degen-1
baseline. The current Hirose mating pair has primary mechanical and electrical
documentation and avoids mixing unverified contact systems.

## Fixed 50-pin Degen-1 logical allocation

The allocation preserves the BIRDS power-pin locations where practical and
reserves adjacent returns. Directions are stated from the perspective of a
plug-in board.

| Pins | Net | Type/direction | Revision-A use |
|---:|---|---|---|
| 1–2 | `I2C_SCL`, `I2C_SDA` | 3.3 V open-drain, bidirectional | low-rate configuration/health bus; pull-ups only on OBC/EPS |
| 3–4 | `UART_TX`, `UART_RX` | 3.3 V logic | primary point-to-point service/mission data pair selected per slot |
| 5–6 | `SPI_SCK`, `SPI_MOSI` | 3.3 V logic, OBC outputs | payload/flash high-rate transfer |
| 7–8 | `SPI_MISO`, `SPI_CS_N` | 3.3 V logic | payload/flash return and slot-specific select |
| 9–10 | `RESET_N`, `WATCHDOG_TOGGLE` | 3.3 V logic | supervised reset and liveness |
| 11–12 | `PWR_ENABLE`, `FAULT_N` | 3.3 V logic | slot power command and fault return |
| 13–14 | `GND_SYS` | power return | paired returns |
| 15–16 | `+3V3_RF` | protected switched power | radio carrier only |
| 17–20 | `GPIO0`–`GPIO3` | 3.3 V logic | fixed slot-specific discretes listed in the slot table |
| 21–22 | `ADC0`, `ADC1` | analog, 0–3.3 V maximum | temperature/current/voltage telemetry only |
| 23–24 | `VBAT_SW_A` | protected switched battery bus | redundant contacts for unregulated branch A |
| 25–26 | `+3V3_B` | regulated power | secondary/switchable logic rail |
| 27–28 | `UART2_TX`, `UART2_RX` | 3.3 V logic | redundant/debug serial channel |
| 29–30 | `SOLAR_RAW_MON`, `VBAT_MON` | scaled analog sense | monitor only; no load current |
| 31–32 | `ADC2`, `ADC3` | analog, 0–3.3 V maximum | slot-specific health inputs |
| 33–34 | `DEPLOY_A`, `DEPLOY_B` | protected command/return | antenna release; absent on other slots |
| 35–36 | `VBAT_SW_B` | protected switched battery bus | redundant contacts for unregulated branch B |
| 37–38 | `PPS`, `TIME_SYNC` | 3.3 V logic | reserved timing pair; normally unpopulated |
| 39–42 | `INHIBIT1_SENSE`–`INHIBIT3_SENSE`, `RBF_SENSE` | 3.3 V protected discrete inputs | OBC/EPS and access board only |
| 43–44 | `RADIO_BUSY`, `RADIO_DIO1` | 3.3 V logic, radio outputs | status and interrupt to OBC |
| 45 | `RESERVED_NC` | no connection at J2 carrier | formerly RADIO_TXEN; module TXEN is driven locally by module DIO2 |
| 46 | `RADIO_RXEN` | 3.3 V logic, OBC output | radio receive-switch control |
| 47–48 | `GND_SYS` | power return | paired returns replacing BIRDS configurable lines |
| 49–50 | `+3V3_A` | always-on regulated power | redundant contacts; safe-state logic |

## Slot population and allowed exceptions

| Slot | Board | Populated interfaces |
|---|---|---|
| J1 | D1-OBC/EPS-001 combined avionics | source/controller for both 3.3 V rails and switched buses; master for digital buses |
| J2 | D1-COM-001 | `+3V3_RF`, SPI, reset, `BUSY`, `DIO1`, and `RXEN`; +3V3_A on 49/50 powers isolation A ports; GPIO0/pin 17 is ISO_OE_N; pin 45 unconnected |
| J3 | D1-CAM-001 payload carrier | protected `+3V3_B` camera branch, UART, power enable and health analogs; no 5 V camera load |
| J4 | D1-FAB-001 front access/safety | inhibit/RBF sense, programming/service UART, battery/solar monitor test points; no mission load |
| J5 | D1-ANT-001 release/antenna board | deployment A/B, release continuity, `+3V3_B`; RF travels by a separate 50 Ω coaxial interface |

No RF signal is routed through the 50-pin connector. Exact coax, RF connector,
cable and bulkhead geometry belong to D1-COM-001/D1-ANT-001.

## Electrical rules

1. All digital pins are 3.3 V logic. A board requiring another logic level must
   contain its own named level translator.
2. Backplane connectors are rated at 1 A per contact by Hirose, but Degen-1 will
   derate power pins after thermal/vacuum analysis. No one contact is credited
   with the manufacturer maximum in the power budget.
3. The two contacts of each power net and its return shall use equal copper paths.
4. `+3V3_A` is the only always-on backplane rail. Other rails default off after
   reset and require explicit supervised enable.
5. Every off-board analog input requires series impedance and clamp analysis.
6. Each slot shall state its maximum inrush, steady and fault current before the
   protection component is selected.
7. Unused pins remain no-connect at the consuming board; they are not tied to
   ground unless this ICD assigns them as ground.

## Required release artifacts

1. Backplane KiCad schematic/PCB and exact connector placement from the BIRDS
   source geometry.
2. Slot-specific pin table with driver, receiver, direction, voltage limits,
   pull state, maximum current, reset state and fault response for every pin.
3. Connector mating-height and board-spacing stack drawing.
4. Copper-current, voltage-drop, grounding and return-path calculations.
5. Harness/connector schedule for solar, battery, RBF, deploy switches and RF.
6. Fabrication outputs, assembly notes, continuity/isolation acceptance test and
   mating-cycle control.

## Evidence limits and conflicts

The logical pin map is a project decision and has not been reviewed in schematic
form. The 90 × 86 mm board outline, 83 × 86 mm component envelope and 22.35 mm
payload allocation are source-backed BIRDS dimensions; their detailed keep-outs
must be transferred from the source drawing/CAD. Connector commercial ratings
do not establish vacuum, vibration, radiation or launch compatibility. Degen-1
must test the assembled interconnect and obtain launch-provider acceptance later.

## Revision B — radio control reconciliation

D1-COM-001 connects module pins 7 and 8 locally (TXEN/DIO2). Backplane
pin 45 is not connected to this net. No MCU output may drive it. The full
radio-carrier connector assignment is `D1-COM-001_pinmap.json`; logical
connectivity is defined, but digital power-off isolation remains unreleased.

Revision C assigns J2 pin 17 to active-low isolation enable, and pins 49/50
to the host-side isolation supply. These do not feed the radio VCC. See
D1-COM-001_isolation.md for the proposed circuit and unresolved release checks.

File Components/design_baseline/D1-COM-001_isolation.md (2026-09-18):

# D1-COM-ISO-001 — radio digital power-domain isolation

Revision A · 2026-09-18 · PROPOSED CUSTOM SUBCIRCUIT

## Purpose and status

Replace undefined direct digital connections between the always-powered OBC
and switchable Ebyte module with an explicit eight-channel isolation design.
This is a spacecraft carrier circuit, not ground hardware. Exact parts below
are selected for detailed circuit work; the subcircuit is not yet fabrication
released, electrically proven or admitted as a completely verified Phase 1 item.

## Exact constituent BOM

| References | Qty | Manufacturer / part | Function and evidence |
|---|---:|---|---|
| U1,U2 | 2 | TI SN74AXC4T774PWR | 4 independent-direction channels per device, PW 16-pin TSSOP; SCES898C p3 pinout, p5–6 electrical limits, p20–22 isolation/control |
| C1–C4 | 4 | KEMET C0603C104K5RACTU | 100 nF nominal, 10%, 50 V X7R, one capacitor at each IC supply pin; exact manufacturer specification archived |
| R1,R2 | 2 | Yageo RC0603FR-074K7L | 4.7 kohm 1%; one OE pull-up per IC; connected in parallel on common control |
| R3–R10 | 8 | Same Yageo part | Module-side defaults: NSS high to RF rail; remaining seven signal nets low to ground |

TI lists the orderable active. Distributor snapshot on 2026-09-18 displayed
4,078 units and USD 1.39 single-unit cut-tape price: two ICs cost USD 2.78 before
shipping/tax; this is not total carrier cost or a purchase. Recheck on procurement.
Order routes:
- https://www.ti.com/product/SN74AXC4T774/part-details/SN74AXC4T774PWR
- https://www.digikey.com/en/products/detail/texas-instruments/SN74AXC4T774PWR/10715472
- https://www.digikey.com/en/products/detail/yageo/RC0603FR-074K7L/730159
- https://www.digikey.com/en/products/detail/kemet/C0603C104K5RACTU/1465623

Supplier URLs, document hashes and retrieval date are in the isolation source
manifest. No guessed device mass is added to the spacecraft budget. IC/resistor
mass remains open; capacitor typical mass is not a guaranteed assembly mass.

## Electrical connections

Canonical editable source: `D1-COM-001_isolation_netlist.json`.
Both ICs: pin 16 VCCA=+3V3_A; pin 15 VCCB=+3V3_RF; pin 10=GND;
pin 9 OE=ISO_OE_N from J2.17. Both rails must stay within 0.65–3.6 V
for specified operation; nominal equal 3.3 V rails are a project decision.
Pin 45 is still NC; DIO2/TXEN is local and is not an isolation channel.

| IC/channel | A pin / B pin / DIR pin | Signal | Direction strap |
|---|---|---|---|
| U1/1 | 3 / 14 / 1 | SCK | DIR to VCCA, host to radio |
| U1/2 | 4 / 13 / 2 | MOSI | DIR to VCCA, host to radio |
| U1/3 | 5 / 12 / 7 | MISO | DIR to GND, radio to host |
| U1/4 | 6 / 11 / 8 | NSS | DIR to VCCA, host to radio |
| U2/1 | 3 / 14 / 1 | NRST | DIR to VCCA, host to radio |
| U2/2 | 4 / 13 / 2 | RXEN | DIR to VCCA, host to radio |
| U2/3 | 5 / 12 / 7 | BUSY | DIR to GND, radio to host |
| U2/4 | 6 / 11 / 8 | DIO1 | DIR to GND, radio to host |

TI p21 cautions against external data pull-ups greater than 7 kohm because
data I/Os have weak internal pull-downs. The 4.7 kohm choice follows that
guidance but does not by itself prove module output-drive compatibility.

## Source-backed limits and bounded consequences

- TI p6 specifies power-off data leakage up to 4 microamp per pin over
  -40 to +85 C, and 8 microamp over -40 to +125 C, at the stated test conditions.
  High impedance does not mean zero leakage or galvanic isolation.
- TI p20 specifies automatic isolation below 100 mV on either supply. It
  does not justify ignoring a slowly decaying/floating rail or a 0.1–0.65 V
  intermediate region. OE must be high during intentional rail transitions.
- Two ICs' combined static supply-current maxima sum to 80 microamp over
  the full IC temperature range (40 each; p6, no output load). This excludes
  dynamic switching, pull resistors, capacitor charging and radio current.
- PW outline p40: 4.9–5.1 by 4.3–4.5 mm body, 6.2–6.6 mm lead span,
  1.2 mm maximum height, 0.65 mm pitch; flash allowances and courtyard still
  apply. No placement or spacecraft fit conclusion follows.
- TI p14 gives up to 5 ns data propagation at both supplies 3.3 +/-0.3 V
  under its test loads. This does not establish permissible end-to-end SPI
  speed; return-path delay, OBC sampling and module timing must be reconciled.

## Startup/shutdown design requirements

1. Reset/high-impedance OBC control leaves OE pulled high. The two 4.7 kohm
   pullups present a nominal 2.35 kohm load when OBC actively drives OE low.
2. Keep OE high while enabling RF power. Initialize host NSS high, reset low,
   SCK/MOSI/RXEN low before enabling the translators. No unspecified delay
   constant is substituted for the radio's reset/startup requirements.
3. Enable only after both rails and GPIO directions are valid. Release radio
   reset using the eventual documented timing sequence.
4. Disable OE before normal radio power-off. A fault may remove RF power
   without software cooperation; analyze this separately using IC isolation
   limits and the EPS rail-discharge network.
5. Reinitialize following brownout; do not treat isolated BUSY/DIO1 readings
   as real radio status. A hardware reset/inhibit scheme must also suppress
   unintended transmit behavior while firmware is not executing normally.

## Required checks before circuit release

Reconcile module and MCU VOH/VOL/VIH/VIL, 4.7 kohm output loads and IC input
edge-rate requirements (10 ns/V); establish supply tolerances/overshoot and
OE rise/fall behavior. Model all leakage paths including limiter, translator
and module to size discharge hardware; no discharge part is silently assumed.
Freeze decoupling effective capacitance/placement, schematic ERC, layout and
SPI timing. Determine device mass/materials and radiation/environmental risk.
Do not use catalog junction-to-ambient thermal resistance as a vacuum model.

Verification later: measure unpowered-rail voltage and individual injection
currents with host inputs high/low, either supply absent, transitions and resets;
capture OE/SPI/NRST waveforms; test all channel directions and recovery. Numeric
system acceptance limits remain pending electrical closure. No physical test
or flight suitability is claimed by this circuit definition.

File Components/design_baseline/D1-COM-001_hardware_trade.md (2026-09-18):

# D1-COM-TRD-002 — onboard radio hardware evidence trade

Revision A · 2026-09-18 · INCOMPLETE TRADE / NO REPLACEMENT SELECTED

Scope is the spacecraft radio and its physical interfaces. Ground systems and
host image-transport development are paused by owner instruction. No new module
has been purchased, tested, qualified or admitted to the complete Phase 1 baseline.

## Current hardware correction

D1-BPB-001 previously allocated RADIO_TXEN at connector pin 45 while D1-COM-001
used local module DIO2 to drive TXEN. The records allowed conflicting interpretations.
Revision B reserves carrier pin 45 as NC. Module pins 7/8 share only the local
switch-control net. D1-COM-001_pinmap.json covers all 22 module and 50 connector
pins. It is intended connectivity, not a released schematic: isolation devices,
default-state networks and exact MCU pins remain required. No direct connection
is thereby approved between powered OBC signals and an unpowered radio.

## Alternative screening

| Candidate | Evidence gained | Remaining selection blocker |
|---|---|---|
| Ebyte E22-400M22S | Full module pin/outline record; corrected current claims; locally archived manufacturer demo | Module-specific TCXO voltage/delay/accuracy and worst-case current evidence still unresolved; generic demo does not close them |
| Dorji DRF1268T | Visually inspected schematic on PDF p4: oscillator is supplied from DIO3; DIO2 and SW control RF switch | Oscillator is only identified as 32 MHz in drawing, with no exact oscillator model or supply rating; schematic is not sufficient to choose DIO3 voltage. Previously recorded power-condition conflict remains |
| HopeRF RFM98W-433S2 | Exact order code on manufacturer V2 p122; register documentation; crystal-based architecture avoids an externally programmed TCXO supply | p110 specifies crystal-selection considerations rather than actual fitted crystal frequency-error bounds; p13 TX/RX currents are typical; exact module mass and controlled thermal/RF bounds remain unverified |

Do not infer that a schematic reveals the ratings of an unnamed oscillator.
The HopeRF part is a candidate to investigate, not an interchangeable replacement:
it changes footprint, register interface, power, temperature constraints and RF
performance. Its datasheet p80 limits +20 dBm transmission to 1% duty cycle and
3:1 antenna VSWR. That restriction cannot be omitted from any eventual hardware
selection. Its p12 operating-temperature table and p80 prose use different ranges;
the narrower p12 table controls screening until resolved. p121 explicitly warns
that its reference schematics may omit required components. Therefore a nominal
reference circuit cannot be treated as a complete fabrication BOM.

## Physical design closure still required

1. Exact oscillator evidence or better documented module/discrete-reference design.
2. Defensible normal and fault current envelopes for EPS protection; typical
   consumption must not masquerade as a guaranteed maximum.
3. Exact back-power isolation, reset/pull network and decoupling parts.
4. RF matching/launch/filter and selected coax connector drawing.
5. Released carrier schematic/PCB with placement/keep-outs and mounting interface.
6. Assembly mass/materials and property evidence for later thermal/structural work.

No thermal simulation or integrated link calculation was performed. Source
provenance is retained in the radio follow-up and alternative JSON manifests.
The new pin map resolves one interface contradiction; it does not close these
remaining release items or establish that the spacecraft is buildable.

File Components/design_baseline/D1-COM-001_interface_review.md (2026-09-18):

# D1-COM-IF-001 — radio interface evidence review

Revision A · 2026-09-18 · DOCUMENT REVIEW / PROJECT REQUIREMENTS

Scope: selected Ebyte E22-400M22S only. No hardware, RF, environmental or
integrated spacecraft test was performed. Website work is paused at owner request.

## Evidence identity

Ebyte User Manual, revision-history entry 1.5 dated 2024-12-31; archived
2026-09-16, re-examined 2026-09-18. PDF page numbers below are one-based file
pages, not printed footers. Pages 5 and 6 were rendered and visually checked;
remaining cited text was extracted with pypdf. No values came from another module.

- Document: https://www.cdebyte.com/pdf-down.aspx?id=3511
- Current product/order route: https://www.cdebyte.com/products/E22-400M22S
- Local archive: `SOURCES/components/Ebyte_E22-400M22S/E22-400M22S_User_Manual.pdf`
- SHA-256: `8c7baff5430e0a9becc7ed778035af546512b0a1c67b81c1d23bddd401f18df1`
- Copyrighted PDF remains local; this review records claims and provenance.

## Documented design -> conflict -> correction

| ID | Documented design | Evidence/conflict | Correction and consequence |
|---|---|---|---|
| COM-C01 | 95/100/105 mA TX bounds and 6/6.5/7 mA RX bounds | PDF p5 lists only 100 and 6.5 in typical column; minimum and maximum cells are blank | Withdraw bounds; do not choose protection thresholds using 105 mA as a guarantee. Source-backed operating envelope still required. |
| COM-C02 | Thickness unknown | PDF p6 explicitly dimensions height 3.00 +/- 0.1 mm | Transfer dimension; module outline becomes 20.0 +/- 0.1 by 14.0 +/- 0.1 by 3.00 +/- 0.1 mm. This is not installed clearance or a carrier footprint release. |
| COM-C03 | 1.8–3.7 V advertised range | PDF p4 feature list says 2.5–3.7 V; p5 operating table says 1.8–3.7 V | Retain recommended nominal 3.3 V. Do not claim full RF performance at 1.8 V; reconcile converter tolerance/ripple/transient limits before release. |
| COM-C04 | VCC supply input | PDF p7 direction column labels VCC output while function describes supply | Treat VCC as power input per supply requirements; preserve apparent documentation error for review, not a new power output. |
| COM-C05 | TCXO exists | PDF p8–9 identifies internal DIO3/TCXO use but does not specify voltage selection, startup delay or ppm bound | Do not copy another module's TCXO setup. Search exact-module manufacturer firmware/settings before driver release and Doppler calculation. |

## Pin-level carrier requirements

The following requirements implement the existing architecture; they are not
claims that a schematic or firmware exists. Module numbering is per PDF p7.

| Pins | Connection | Evidence / release condition |
|---|---|---|
| 1–5,10–12,20,22 | Ground | Manufacturer p7; continuous return and RF layout require PCB review |
| 9 | Protected 3.3 V input | Manufacturer p5,7; capacitor exact parts and power-off behavior unresolved |
| 6 | OBC RXEN output | Active high, p7; keep low outside receive as project requirement |
| 7,8 | TXEN wired to DIO2 | Manufacturer p8–9; do not additionally drive DIO2 with an MCU output |
| 13 | DIO1 to OBC interrupt input | Manufacturer p7; IRQ configuration and OBC physical pin not released |
| 14 | BUSY to OBC input | Manufacturer p7; timeout/recovery logic required, not endless polling |
| 15 | Active-low reset from OBC | Manufacturer p7; timing and power-off isolation require chip documentation |
| 16 | MISO to OBC input | Manufacturer p7; shared-bus contention analysis required |
| 17,18,19 | MOSI,SCK,NSS from OBC | Manufacturer p7; no 5 V signaling; power-off isolation unresolved |
| 21 | 50-ohm RF carrier path | Manufacturer p7; exact launch/filter/antenna path remains custom design |

## Initialization release checklist

1. Reconcile exact module TCXO control voltage/startup time against manufacturer
   example source and SX1268 commands. Record file revision/hash and line references.
2. Define reset, BUSY timeout and command-status error recovery from chip manual.
3. Configure DIO2 switch control while separately driving RXEN. Define safe
   transitions that never request simultaneous transmit and receive paths.
4. Define calibration, regulator, PA and OCP configuration for SX1268 and this
   module, not a substituted SX1262 board. Require exact register/command table.
5. Select packet type and full modulation/packet parameters only after public
   evidence supports sensitivity, bandwidth and oscillator-error analysis.
6. Define power-off GPIO states and verify no back-power path in the schematic.
7. Release the same waveform/configuration on ground and flight implementations.

These are incomplete release tasks, not a working initialization algorithm.

## Verification path and priority

Public-information work next: retrieve exact Ebyte firmware/settings; reconcile
TCXO configuration; source chip-level command/timing evidence; evaluate a better
documented module if critical evidence cannot be obtained. Do not immediately
contact the vendor or substitute assumed limits. A custom carrier does not make
missing COTS properties acceptable.

Later bench procedure: inspect orientation/pin continuity; verify protected supply
and zero unintended power-off injection against released limits; capture reset,
BUSY, SPI and switch controls; exercise timeout recovery; conduct attenuated
two-radio packet tests at both planning frequencies; characterize power and
current across released voltage/temperature conditions. Numeric acceptance limits
cannot be issued until the corresponding source/design bounds are released.

No evidence supports declaring the ground modem, orbital link, current limiter,
radio flight suitability or full spacecraft functional at this stage.

## Public-source follow-up — 2026-09-18

Retrieved the demo linked directly from the exact Ebyte product download page:
https://www.cdebyte.com/products/E22-400M22S/4 . Exact download URLs and hashes
are in `D1-COM-001_followup_sources.json`. Local vendor archives are excluded
from public Git pending redistribution review.

The nested `sx126x-driver.zip` is a generic Semtech driver distribution for
Nucleo boards. `src/radio/sx126x/sx126x.c` line 95 requests 1.7 V only inside
`USE_TCXO`; `sx126x.h` line 34 defines 5 ms under that conditional. None of
the six supplied Keil project files contains `USE_TCXO`. These values are
**example code**, not verified E22-400M22S operating requirements. No driver
was compiled, executed, flashed or tested. The exact-module configuration
gap COM-C05 remains open. Chinese manual PDF p6 also describes DIO3 powering
the TCXO without supplying the needed voltage/startup bounds in that passage.

Reproduce the source inspection, from repository root:

```text
python Components/design_baseline/audit_radio_demo.py SOURCES/components/Ebyte_E22-400M22S/manufacturer_demo_2026-09-18.zip
```

Compare output with `D1-COM-001_demo_audit.json`. This checks source contents
and hashes only; it cannot verify behavior or establish electrical ratings.

### Alternative actively examined: Dorji DRF1268T

Manufacturer datasheet Rev 1.00 Dec 2018 has a pin table (p2), electrical and
absolute limits (p3), circuit schematic (p4), and mechanical drawing (p5).
It explicitly states a +/-1 ppm TCXO (p2), but the conditions covering that
accuracy are not established by that statement. Its operating band is
410–460 MHz, while the power row on p3 specifies a 915 MHz condition. That
row cannot substantiate output power in our band. Current commercial
obtainability, exact mass, oscillator implementation/configuration, and
condition-specific current/RF limits still require evidence review.

Decision: **CANDIDATE / EVIDENCE INCOMPLETE, not a replacement selection**.
Do not silently transfer its ppm value or circuit to Ebyte. Next engineering
action is to examine its schematic and official example/settings alongside
current manufacturer product evidence, then compare against Ebyte and a
crystal-based documented alternative. If neither module meets required
properties, a custom RF board using a fully documented transceiver/reference
design is a trade candidate, not a released custom part by declaration.

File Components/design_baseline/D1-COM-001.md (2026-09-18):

# D1-COM-001 - UHF command, telemetry and image radio

Revision B - 2026-09-18  
State: **CUSTOM/TO BE VERIFIED - exact RF module selected; carrier, waveform release and link closure open**

## Selection

Degen-1 selects one Chengdu Ebyte **`E22-400M22S`** SPI radio module on a
project-designed carrier. The module is based on Semtech `SX1268`, includes the
32 MHz TCXO and RF switch, and is sold by its manufacturer. It replaces the
earlier ADDNICS candidate for the detailed-design baseline.

The ADDNICS `ADD1397B` Rev. C ICD remains valuable heritage evidence but is not
the selected part: the public ICD leaves mass blank, the current BIRDS record
names `ADD1397CF`, and the ADDNICS public product page does not identify the
orderable configuration. Those conflicts prevent an auditable exact selection.

## Manufacturer-established module properties

| Property | Value used by Degen-1 |
|---|---|
| Manufacturer/model | Chengdu Ebyte Electronic Technology Co., Ltd. `E22-400M22S` |
| Core transceiver | Semtech `SX1268` |
| Frequency range | 410-493 MHz |
| Modulation capability | LoRa and conventional FSK/GFSK through the SX1268 command set |
| Maximum RF output | 22.3 dBm specified maximum; 21.4 dBm specified minimum at the maximum-power setting |
| Supply | 1.8-3.7 V; 3.3 V recommended |
| Transmit current | 100 mA typical; guaranteed maximum NOT established by archived manual; prior 95/105 mA bounds withdrawn |
| Receive current | 6.5 mA typical; guaranteed minimum/maximum NOT established by archived manual |
| Sleep current | 180 nA typical |
| Operating temperature | -40 to +85 degrees C |
| SPI | 0-10 MHz, direct transceiver command interface |
| FIFO | 256 bytes |
| RF port | 50 ohm IPEX or castellated pad; castellated 50 ohm port is the Degen-1 configuration |
| Size | 20.0 +/- 0.1 x 14.0 +/- 0.1 x 3.00 +/- 0.1 mm; manual PDF page 6; installed solder/clearance allowance not included |
| Mass | 1.5 +/- 0.1 g |

No range claim from the manufacturer is used as an orbital link result. The
published 7 km demonstration has terrestrial conditions and is not relevant to
a 500-2500 km slant-range link.

## Module pin use

| Module pins | Signal | Degen-1 use |
|---:|---|---|
| 1-5, 10-12, 20, 22 | `GND` | uninterrupted RF/digital ground plane and carrier bonding |
| 6 | `RXEN` | OBC-controlled RF receive switch, defined low at reset |
| 7 | `TXEN` | driven by SX1268 `DIO2` as recommended; test point provided |
| 8 | `DIO2` | RF-switch transmit control |
| 9 | `VCC` | protected `+3V3_RF`; local ceramic bulk/high-frequency decoupling |
| 13 | `DIO1` | packet/timeout interrupt to OBC |
| 14 | `BUSY` | busy input to OBC; every SPI transaction waits for deassertion |
| 15 | `NRST` | supervised active-low reset from OBC |
| 16-19 | `MISO`, `MOSI`, `SCK`, `NSS` | dedicated 3.3 V SPI bus |
| 21 | `ANT` | controlled-impedance 50 ohm trace to the selected RF connector/filter/antenna assembly |

The module is a radio transceiver, not a modem with a private host protocol. The
OBC issues the public SX1268 SPI commands and implements all Degen-1 packet,
authentication, retry, image-segmentation and Doppler scheduling behavior.

## Power and fault containment

A second TI `TPS2553DRVR-1` on D1-EPS-001 supplies `+3V3_RF`. Its latch-off
response prevents an overcurrented module from repeatedly loading the bus. The
exact `R_ILIM` remains OPEN: the prior claimed 105 mA manufacturer maximum
is unsupported by the archived manual and is withdrawn. Establish an evidence-backed
operating-current envelope, carrier consumption, inrush and converter fault limits
before selecting the limiter resistor. Typical current cannot close worst-case protection. The radio defaults unpowered after reset and after any watchdog or
brownout event.

The module is commanded to standby before its supply is removed. The carrier
shall prevent SPI/control pins from back-powering an unpowered module.

## Provisional link definition

The design uses a half-duplex UHF amateur-satellite link. Frequencies are
configuration parameters and cannot be finalized until IARU coordination and
FCC authorization. Analysis shall use 435.8 MHz uplink and 437.4 MHz downlink as
explicit planning frequencies; these are not assignments or authorization to
transmit.

The waveform trade is constrained to modes the selected module implements from
public commands. Revision A carries LoRa and GFSK as analysis candidates. The
released choice must close:

- 500 km nominal and 2500 km conservative slant-range budgets;
- maximum LEO Doppler and TCXO error without relying on an unavailable private
  synchronization feature;
- occupied bandwidth and applicable amateur-satellite coordination limits;
- time-on-air for health telemetry, command acknowledgement and a representative
  piCAM image;
- receiver sensitivity at the exact selected bitrate/bandwidth; and
- at least 3 dB calculated implementation margin before the physical-test phase.

No earlier AX.25/4800-bps link result transfers to this radio.

## Degen-1 application frame

The application layer shall be public and implemented identically in flight and
ground software. Each variable-length packet contains, in order:

1. protocol version and packet type;
2. spacecraft identifier;
3. monotonically increasing 32-bit sequence number;
4. mission-time field;
5. payload length and payload;
6. CRC-32 over the application header and payload; and
7. for uplink commands, an AES-128-CMAC authentication tag and persistent replay
   check.

Command payload remains intelligible; authentication is not represented as
regulatory permission to encrypt amateur traffic. Tag length, byte order,
polynomial, exact field widths, key loading and lost-state recovery must be fixed
in the released wire-protocol document and test vectors. Critical commands
include acknowledgement and persistent execution result. Radio-disable commands
survive OBC reset.

Image data is segmented by image identifier, fragment number, total fragments and
byte offset. Ground software writes a JPEG only after length, CRC and JPEG
start/end-marker validation; missing fragments can be requested again.

## Custom carrier release requirements

1. KiCad schematic, PCB, fabrication files and exact BOM for the module carrier.
2. Manufacturer footprint transfer and courtyard, including module thickness.
3. Controlled-impedance stack-up, RF launch, connector, filter and coax schedule.
4. Input protection, local decoupling, load-switch and digital back-power analysis.
5. RF enclosure/keep-out and conducted/radiated EMC provisions.
6. SX1268 initialization register/command table and public flight/ground driver.
7. Complete wire protocol with golden test vectors and fault cases.
8. Link, Doppler, time-on-air and duty-cycle calculations.
9. Conducted power, harmonics, sensitivity, packet-error-rate, thermal-vacuum and
   end-to-end ground-link verification procedures for the later physical phase.

## Primary evidence

- Ebyte `E22-400M22S` product page and purchase route:  
  https://www.cdebyte.com/products/E22-400M22S
- Ebyte *E22-400M22S User Manual*, version 1.5, 2024-12-31:  
  `SOURCES/components/Ebyte_E22-400M22S/E22-400M22S_User_Manual.pdf`
- Semtech `SX1268` current product record and datasheet:  
  https://www.semtech.com/products/wireless-rf/lora-connect/sx1268
- BIRDS ADDNICS heritage interface document:  
  https://github.com/BIRDSOpenSource/BIRDS4-COM

## Evidence limits

The module is industrial COTS and is not documented as radiation hardened,
vacuum qualified or launch qualified. The Ebyte manual does not provide orbital
radiation, outgassing, random-vibration or thermal-vacuum evidence. Selection for
this education-grade theoretical design depends on fault containment, a defined
physical verification program and later expert RF review; it is not a claim of
flight readiness.

## Revision B evidence correction

See [radio interface review](D1-COM-001_interface_review.md). This revision
closes the nominal module-height transcription and withdraws unsupported current
bounds. It does not admit the radio to the completed Phase 1 baseline.

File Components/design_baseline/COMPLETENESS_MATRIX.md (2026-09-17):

# D1-DD-CMP-001 - detailed-design component completeness matrix

Revision A - 2026-09-16  
Status: **ACTIVE CONTROL REGISTER - THEORETICAL DESIGN INCOMPLETE**

This register controls the BIRDS-derived detailed design selected by
D1-TRD-ARCH-001. The earlier `Proposed_Operating_Component_Set` and
`phase1_closure` register remain historical records of the rejected mixed-vendor
proposal.

`SELECTED` means that an exact COTS item or custom architecture has been chosen.
It does not mean the component is qualified or that its custom release package is
complete.

## Flight segment

| Function | Controlled item | Identity/state | Remaining design closure |
|---|---|---|---|
| 1U rails and load structure | D1-STR-001 | CUSTOM/TO BE VERIFIED; pinned BIRDS-4 22-instance frame geometry, 6061-T6 and controlled rail finish selected | release Degen-native parametric parts/drawings, tolerances, interfaces, fasteners, inspection plan and structural analyses |
| Five solar panels | D1-SOL-001 | CUSTOM; AZUR `81442` cells and YAGEO Nexensos `32208571` Pt1000 sensors selected | PCB/mechanical variants, RTD attachment/readout, harness transitions and panel acceptance release |
| Battery energy storage | D1-BAT-001 | CUSTOM; Panasonic `BK120AAHU` 3S2P selected | pack drawing/BOM, protection, cell curves, screening and exact mass |
| Power conversion/charging/distribution | D1-EPS-001 | CUSTOM; principal ICs selected | full schematic/BOM/layout/calculations and release tests |
| Launch inhibits, RBF and service access | D1-FAB-001 | CUSTOM/TO BE VERIFIED; exact switches, two RBF pairs, seven power devices, gate network and service connector selected; Boolean all-state/single-fault logic passes | release schematic/PCB, actuator/access geometry, source-to-hazard fault tree, worst-case circuit analysis and verification procedures |
| OBC and safe-state control | D1-OBC-001 | CUSTOM; architecture under revision | freeze current MCU, memory, clocks, supervisors and full board release |
| Passive backplane | D1-BPB-001 | CUSTOM; exact Hirose pair and logical map selected | geometry, slot tables, current/return analysis and fabrication release |
| UHF transceiver | D1-COM-001 | CUSTOM carrier; Ebyte `E22-400M22S` selected | carrier, RF network, waveform, protocol, link and EMC closure |
| UHF antenna and deployment | D1-ANT-001 | CUSTOM/TO BE VERIFIED; OreSat-derived 436.5 MHz canted turnstile and Quetzal-derived four-channel release selected | release RF/end-panel PCB, elements, pivots, line, complete BOM, harness interface, EM/structural analyses and RF/deployment verification |
| Earth camera | D1-CAM-001 | SkyFox `piCAM/FM` selected | connector suffix, current limit, STEP/configuration and carrier release |
| Passive attitude stabilization | D1-ADCS-001 | CUSTOM/TO BE VERIFIED; K&J `D84` plus two 95 mm × 1 mm HyMu 80 rods selected | release rod/retainer drawings; characterize magnet, rod loops and integrated residual dipole; cage test and probability/dynamics analysis |
| Harnesses | D1-HAR-001 | CUSTOM/TO BE VERIFIED; 11 flight and one ground harness identified; Spec 55 wire, JST PA connectors, camera connector family, exact 100 mm U.FL coax and PTFE lacing selected | release CAD-routed cut lengths, camera contact finish, solar-panel lead transitions, strain-relief drawings, voltage-drop/thermal/RF analyses and fabrication/inspection data |
| Mounting/bonding hardware | D1-MECH-HW-001 | OPEN | itemized fasteners, locking, torque, bonding and access sequence |
| Thermal materials/interfaces | D1-THM-001 | OPEN | exact surface finishes, interface materials, heater decision and thermal-node evidence |
| Flight software | D1-FSW-001 | OPEN | reproducible source/build, state machine, drivers, protocol, storage and fault tests |

## Ground segment

| Function | Controlled item | Identity/state | Remaining design closure |
|---|---|---|---|
| Matching UHF radio/modem | D1-GS-RAD-001 | OPEN; same E22 module is leading architecture | USB/SPI controller, enclosure, supply and public software release |
| Directional circular antenna | D1-GS-ANT-001 | OPEN | exact antenna with pattern/gain evidence and frequency coverage |
| Pointing | D1-GS-POINT-001 | OPEN | select manual sighting or exact az/el rotator/controller and tracking procedure |
| Feedline/filter/T-R path | D1-GS-RF-001 | OPEN | exact cable/connectors/filter/protection and loss/noise/power budget |
| Station computer | D1-GS-PC-001 | OPEN | minimum documented hardware/software interface and reproducible image |
| Pass prediction/control software | D1-GS-SW-001 | OPEN | open-source package versions, orbit input, Doppler schedule, command safeguards |
| Image reconstruction/archive | D1-GS-IMG-001 | OPEN | released decoder, integrity checks, storage and operator workflow |
| Image printing | D1-GS-PRN-001 | OPEN | exact printer/driver/paper interface or documented ordinary-PC print requirement |
| Site power, mast and protection | D1-GS-SITE-001 | SITE-DEPENDENT CUSTOM | conservative portable configuration plus site-specific safety path |

## Current result

Twelve detailed component records exist. Exact selections now control the battery
cell, camera, UHF module, solar-cell assembly, stack connectors, principal EPS
parts, passive-ADCS magnet/material geometry, the principal antenna feed and
release parts, nominal 1U frame geometry/material, and the launch-inhibit/RBF
principal hardware and topology. The design is not yet
buildable under D1-DES-STD-001 because structure drawings/tolerances/analysis,
released antenna fabrication data, ADCS retainers and measured
magnetic properties, released harness routing/terminations, released avionics and the ground chain are
incomplete. No entry in this matrix is physical test evidence.

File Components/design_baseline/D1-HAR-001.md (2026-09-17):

# D1-HAR-001 — flight and service harness baseline

Revision A · 2026-09-17  
State: **CUSTOM/TO BE VERIFIED — complete harness topology and principal COTS materials selected; CAD-routed lengths, panel terminations and camera contact finish remain open**

## Scope and completeness result

This record accounts for every wire or cable that crosses between presently
selected Degen-1 assemblies. The five plug-in electronics boards communicate
through D1-BPB-001's fixed 50-pin connectors; separate board-to-board signal
cables are therefore prohibited. D1-ADCS-001 is passive and has no electrical
harness. The two RBF jacks are mounted directly on D1-FAB-001 and have no
flight pigtails.

The remaining flight harness set is one battery loom, five panel looms, three
independent deployer-switch leads, one camera cable and one RF coax. One
removable service cable is ground support equipment and does not fly. The
machine-readable schedule is `harness_schedule.csv`.

## Controlled material set

| Use | Exact manufacturer part | Controlled properties and limit |
|---|---|---|
| Flight power wire, red | TE Connectivity/Raychem `55A0111-24-2` | Active Spec 55, 24 AWG, 19/36 tin-plated copper, red radiation-crosslinked modified ETFE, 0.94 mm OD, -65 to +150 °C, 600 V |
| Flight power return, black | TE Connectivity/Raychem `55A0111-24-0` | Same construction/rating, black |
| Flight signal wire, white | TE Connectivity/Raychem `55A0111-26-9` | Active Spec 55, 26 AWG, 19/38 tin-plated copper, white radiation-crosslinked modified ETFE, 0.81 mm OD, -65 to +150 °C, 600 V |
| Flight signal return, black | TE Connectivity/Raychem `55A0111-26-0` | Same construction/rating, black |
| Standard locking flight connector contacts | JST `SPHD-001T-P0.5` | Tin-plated copper-alloy crimp contact; AWG 26–22, 1.0–1.5 mm insulation OD |
| Battery connector | JST `PAP-06V-S` housing to `B06B-PASK-1(LF)(SN)` header | Six positions, polarized secure lock, 2.0 mm pitch |
| Solar connector, each panel | JST `PAP-04V-S` housing to `B04B-PASK-1(LF)(SN)` header | Four positions, polarized secure lock, 2.0 mm pitch |
| Deployer-switch connector, each switch | JST `PAP-02V-S` housing to `B02B-PASK-1(LF)(SN)` header | Two positions, polarized secure lock, 2.0 mm pitch |
| Service connector | JST `PAP-10V-S` housing to D1-FAB `B10B-PASK-1(LF)(SN)` | Ten positions; ground cable only; pin map controlled by D1-FAB-001 |
| Camera cable housings | Molex `510210600` x2 | Six-position 1.25 mm PicoBlade receptacle housing; mates with series 53261 |
| Camera-carrier header | Molex `532610671` | Exact six-position right-angle SMT tin-plated PicoBlade header, 30-cycle commercial rating |
| Camera contacts | **OPEN — `500798001` only if the delivered camera header is tin-plated** | The piCAM datasheet omits its 53261 suffix/contact finish. Gold-flash `500798020` is not silently substituted; mating finishes must match. |
| RF cable assembly | Hirose `UFL-2LPA-068Y2T-A-100`, CL0321-7101-0-08 | Exact 100 mm, 50-ohm, two-right-angle U.FL cable assembly, 1.13 mm cable, -40 to +105 °C, 0.41 g, 30 mating cycles |
| Radio-carrier RF receptacle | Hirose `U.FL-R-SMT-1(10)` | Same exact receptacle already selected at D1-ANT-001; one additional unit on D1-COM-001 carrier |
| Flight bundle lacing | Western Filament `TOF15`, uncoated | A-A-52082 PTFE flat braid, size 4, nominal 0.065 × 0.011 in, 15 lbf minimum break strength; manufacturer recommends the family for hard-vacuum/low-outgassing use |

The JST PA family rating is 3 A at AWG 22 and -40 to +105 °C. Those catalog
limits are not adopted as spacecraft current or thermal qualification. Degen-1
uses two parallel 24 AWG positive contacts and two parallel 24 AWG return
contacts on the battery interface. The later voltage-drop/thermal analysis must
use contact resistance, wire resistance, temperature and vacuum derating rather
than the headline family rating.

## Harness schedule and pin maps

Cut lengths below are **PROJECT ROUTING ALLOCATIONS**, measured conductor end to
end before termination. They permit a reproducible preliminary BOM, but they do
not become released fabrication lengths until the full CAD route includes bend
radius, connector backshell/strain relief, service loop, clamp points and
termination strip allowance. A harness drawing shall replace each allocation
with a tolerance-controlled cut table before the theoretical-buildability gate.

### HAR-FLT-001 — battery to EPS, allocated 150 mm

The pack end is a direct, strain-relieved termination on the custom battery
protection/interconnect PCB. The EPS end is `PAP-06V-S`.

| Cavity | Net | Wire |
|---:|---|---|
| 1 | `BAT_POS_A` | `55A0111-24-2` red |
| 2 | `BAT_POS_B` | `55A0111-24-2` red |
| 3 | `BAT_NEG_A` | `55A0111-24-0` black |
| 4 | `BAT_NEG_B` | `55A0111-24-0` black |
| 5 | `BAT_NTC_HI` | `55A0111-26-9` white |
| 6 | `BAT_NTC_RET` | `55A0111-26-0` black |

### HAR-FLT-002 through -006 — five solar panels, allocated 180 mm each

IDs are `SOL_X_POS`, `SOL_X_NEG`, `SOL_Y_POS`, `SOL_Y_NEG`, and `SOL_Z_NEG`.
The panel end is directly soldered and strain relieved on the panel PCB; the EPS
end uses `PAP-04V-S`. The five power pairs terminate on independent protected
panel inputs. They are not paralleled in a cable splice.

| Cavity | Net | Wire |
|---:|---|---|
| 1 | `<FACE>_PV_POS` | `55A0111-24-2` red |
| 2 | `<FACE>_PV_NEG` | `55A0111-24-0` black |
| 3 | `<FACE>_RTD_HI` | `55A0111-26-9` white |
| 4 | `<FACE>_RTD_RET` | `55A0111-26-0` black |

Cavities 3–4 connect to the exact YAGEO Nexensos M222 `32208571` Pt1000 selected
by D1-SOL-001. The sensor-to-Spec-55 transition, attachment and strain relief
remain unreleased custom panel details; the 10 mm bare sensor leads do not span
the panel-to-EPS route.

### HAR-FLT-007 through -009 — three deployer switches, 180 mm each

Each `SDS002RULC` is on its own retained switch tab/PCB. No conductor or
connector is shared between switch channels. The D1-FAB end uses `PAP-02V-S`.

| Cavity | Net | Wire |
|---:|---|---|
| 1 | `INHIBIT_<N>_CONTACT` | `55A0111-26-9` white |
| 2 | `INHIBIT_<N>_RETURN` | `55A0111-26-0` black |

### HAR-FLT-010 — camera to carrier, allocated 120 mm

Both ends use `510210600`; the carrier contains `532610671`. Cavity numbers are
kept pin-for-pin so the cable is inspectable without hidden crossovers.

| Cavity | Camera signal | Carrier net | Wire |
|---:|---|---|---|
| 1 | `VDD` | `+3V3_B_CAM` | `55A0111-26-9` white, marker `CAM_VDD` |
| 2 | `ON` | `CAM_ON` | same wire, marker `CAM_ON` |
| 3 | `RXD` | `OBC_UART_TX_TO_CAM` | same wire, marker `CAM_RX` |
| 4 | `TXD` | `OBC_UART_RX_FROM_CAM` | same wire, marker `CAM_TX` |
| 5 | `FLASH` | no connect at carrier | same wire omitted; cavity deliberately empty |
| 6 | `GND` | `CAM_GND` | `55A0111-26-0` black |

The installed camera connector finish is a current evidence gap. This harness
cannot be fabrication released until SkyFox's delivered connector suffix or an
incoming inspection establishes the mating finish.

### HAR-FLT-011 — radio carrier to antenna board

Use one unmodified Hirose `UFL-2LPA-068Y2T-A-100`. Both PCB ends use
`U.FL-R-SMT-1(10)`. The assembly has no field-installed RF crimp. CAD must prove
that 100 mm reaches with the manufacturer's bend limits, does not cross a sharp
edge or release mechanism, and can be positively restrained without loading
either push-on connector.

### HAR-GSE-001 — removable service cable, 1,000 mm allocation

The spacecraft end uses `PAP-10V-S` and ten `SPHD-001T-P0.5` contacts with
26 AWG Spec 55 wire. The opposite end terminates on the later D1-GS-EGSE-001
breakout, never directly on an uncontrolled USB-UART adapter or power supply.
No conductor supplies spacecraft power. This cable is removed before flight.

## Calculated preliminary quantities

Using the allocations above, the flight build requires 2.40 m of 24 AWG wire,
3.78 m of 26 AWG wire before process scrap, one 100 mm coax assembly, six JST
panel/battery housings, three JST switch housings, 32 JST flight contacts, two
camera housings and ten camera contacts for the five populated conductors. The service cable adds
10.0 m of 26 AWG ground-use wire and ten JST contacts.

These quantities are **CALCULATED from unreleased routing allocations**. No
flight-harness mass is claimed because the final wire lengths, camera contact,
solar-panel lead transitions, strain-relief pieces and lacing quantity are not
released.

## Assembly and verification requirements

1. Produce a drawing for each serialized harness with end views, cavity numbers,
   net names, wire part/color/gauge, cut and strip lengths, tolerances, twist
   instructions, branch points, lacing, labels and allowable repair method.
2. Fabricate to NASA-STD-8739.4A principles using trained personnel and the
   connector manufacturer's controlled crimp tooling/process. This project has
   not certified any assembler to that standard.
3. Use no inline flight splice, solder-tinned crimp conductor, consumer PVC
   wire, adhesive cable tie mount, or nylon zip tie. Any necessary splice opens
   this record and requires an exact qualified splice system.
4. Key, label or physically separate adjacent connectors. Identical solar-panel
   connectors are acceptable only because their pin maps are identical; face
   identity is carried by harness ID and EPS channel label.
5. Provide independent strain relief before every PCB termination. Harness
   restraint clips and fasteners are D1-MECH-HW-001 items; solder joints and
   push-on U.FL connectors do not carry harness inertia.
6. Inspect 100% for part identity, strip/crimp dimensions, insulation support,
   contact seating, pin assignment, workmanship, length and damage.
7. Test 100% continuity and isolation before and after installation; record
   four-wire resistance for each power conductor and the complete RF cable's
   insertion/return loss over the released band.
8. Repeat continuity/isolation after vibration and thermal-vacuum testing.
9. Close voltage drop and wire/contact temperature at worst-case current and
   temperature before release. The present wire voltage rating is irrelevant to
   this low-voltage current/thermal calculation.
10. Control connector mating counts; the U.FL and PicoBlade public records each
    specify 30 cycles, which is not a target integration count.

## Evidence, procurement and limitations

- TE/Raychem Spec 55 wire product pages and Issue 5 specification:
  https://www.te.com/en/product-2160283004.html
- JST PA family:
  https://www.jst-mfg.com/product/pdf/eng/ePA-F.pdf
- Molex PicoBlade 51021/50079/53261 family:
  https://www.molex.com/en-us/products/series-chart/51021
- Hirose exact RF cable assembly:
  https://www.hirose.com/product/p/CL0321-7101-0-08
- Western Filament A-A-52082 PTFE lacing:
  https://wfilament.com/a-a-52082/
- NASA-STD-8739.4A with Change 4:
  https://standards.nasa.gov/sites/default/files/standards/NASA/A/4/nasa-std-87394a_w_change_4_0.pdf

Exact TE, Hirose and NASA documents and the Western Filament manufacturer page
are archived and hashed. The official Molex product specification was reviewed
through the public manufacturer endpoint, but repeated automated archive
downloads timed out; no third-party substitute is treated as primary evidence.
The previously archived JST PA-family PDF is reused.

A current authorized-distributor snapshot on 2026-09-17 showed red 24 AWG Spec
55 wire at USD 1.37/ft in single-foot quantity and black 26 AWG at USD 1.47/ft.
These are procurement snapshots, not controlled future prices. Public unit
prices for the exact connectors, coax and lacing have not all been captured, so
the flight-harness cost remains **OPEN** rather than fabricated from estimates.

No harness has been fabricated, inspected, electrically tested, vibrated,
thermal-vacuum tested, or independently reviewed. Commercial connector ratings
and aerospace wire-family qualification do not qualify the integrated Degen-1
harness for launch or orbit.

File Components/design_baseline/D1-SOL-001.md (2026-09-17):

# D1-SOL-001 - body-mounted solar panels

Revision A - 2026-09-16  
State: **CUSTOM/TO BE VERIFIED - exact cell assembly and five-face topology selected; panel PCB release open**

## Exact cell assembly

Each Degen-1 solar panel uses two series-connected AZUR SPACE
**3G30A-Advanced 4x8 SCA/CIC, material part number `81442`, drawing
`ZP-0004289`**. The selected assembly includes the 3G30C triple-junction cell,
corner-mounted silicon bypass diode, welded out-of-plane silver-coated Kovar
interconnects, 100 micrometre AR-coated coverglass and space-grade adhesive.

The bare-cell part `81441` is not interchangeable because it omits the selected
coverglass, diode and interconnect assembly.

## Spacecraft population

| Face group | Quantity | Configuration |
|---|---:|---|
| Four rail-side faces | 4 panels / 8 SCAs | two `81442` SCAs in series on each panel |
| Nadir/opposite-camera end face | 1 panel / 2 SCAs | two `81442` SCAs in series; final antenna stow routing must preserve the active area |
| Camera end face | 0 | camera aperture and antenna-deployment hardware; no generation credited |
| Total | 5 panels / 10 SCAs | five separately isolated series strings paralleled at D1-EPS-001 |

The face naming is a project coordinate decision; “nadir” describes the intended
camera direction and does not claim active attitude pointing.

## Manufacturer-established SCA properties

| Property | `81442` value |
|---|---:|
| Outer size | 40.15 +/- 0.05 x 80.15 +/- 0.05 mm |
| Glazed area | 31.13 cm2; active cell area 30.18 cm2 |
| Thickness | 290 +/- 50 micrometres |
| Average mass | no more than 3.6 g |
| BOL `Voc` / `Isc` | 2.700 V / 0.515 A, typical at stated AM0 condition |
| BOL `Vmp` / `Imp` | 2.411 V / 0.499 A, typical at stated AM0 condition |
| 1E15 e-/cm2 `Vmp` / `Imp` | 2.230 V / 0.480 A, typical at stated test condition |
| BOL efficiency | 29.2% at 1367 W/m2, typical |
| `Vmp` temperature coefficient | -6.7 mV/degree C BOL; -7.2 mV/degree C at 1E15 e-/cm2 |
| Qualification stated by manufacturer | ECSS-E-ST-20-08C Rev. 1 qualified; technology/on-orbit heritage stated |

The selected ten SCAs contribute no more than 36 g before panel PCBs, harnesses,
coatings and mounting hardware.
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

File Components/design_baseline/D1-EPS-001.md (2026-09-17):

# D1-EPS-001 — electrical power and launch-inhibit board

Revision A · 2026-09-16  
State: **CUSTOM/TO BE VERIFIED — topology and principal parts selected; schematic/layout not released**

## Function

D1-EPS-001 collects power from body-mounted solar panels, charges the 3S2P
NiMH battery, enforces cold-launch isolation, creates the regulated spacecraft
rails, switches high-load branches and measures power-system health. It is a new
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

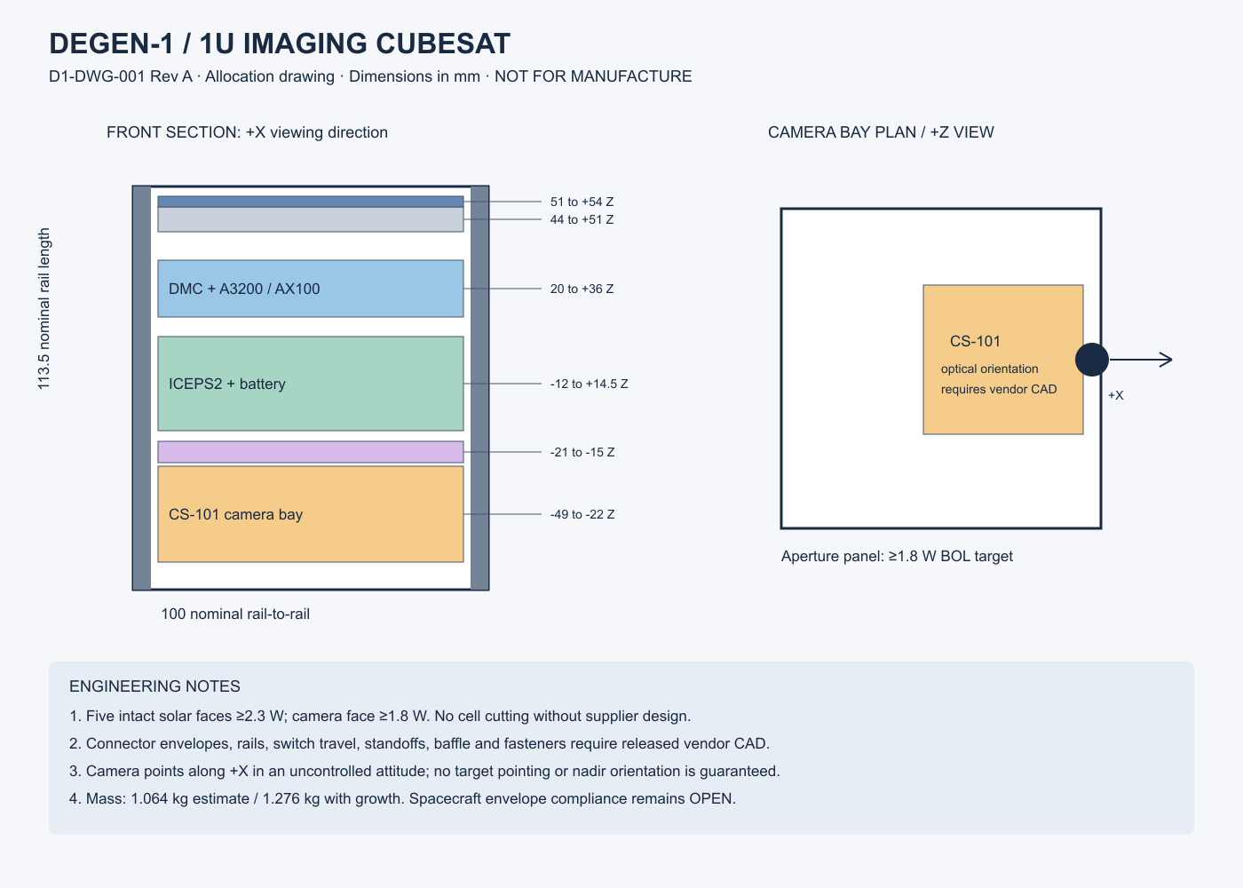
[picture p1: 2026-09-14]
drawings/D1-DWG-001_Layout.png

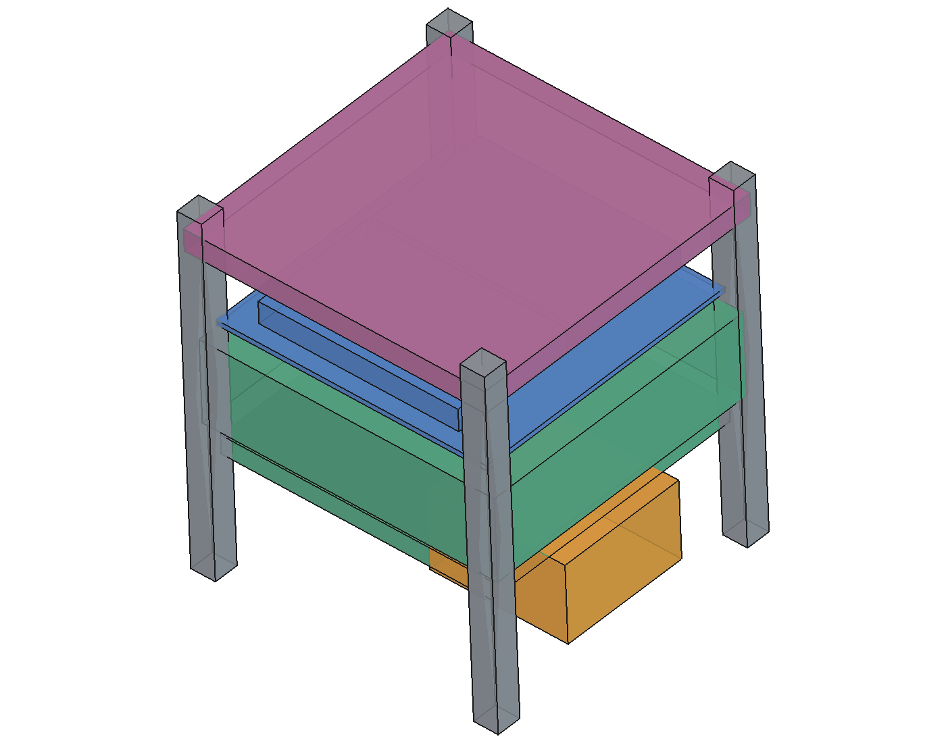
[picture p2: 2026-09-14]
drawings/freecad/exports/internal.png

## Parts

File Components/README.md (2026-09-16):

# DEGENERATE-1 component audit

Audit date: 2026-09-15  
Scope: the 16 lines B01–B16 already present in `procurement/BOM.csv`

This folder answers what is currently known about the cost, order route, availability, size, mass, power, interfaces, required configuration, environmental evidence and procurement blockers for every component already supported by the project record. It does not introduce any new spacecraft component. The solar-panel family appears on four BOM lines because the documented spacecraft requires four different procurement configurations. The five integration-vendor lines remain custom assemblies/lots because their constituent designs have not been released.

The later `Phase1_Functional_Audit.md` supersedes this file for Phase 1 admission.
It tests required functions as well as BOM rows. Under D1-CMP-STD-001, no
component currently passes the complete mission-relevant public-evidence gate.
The sortable `Phase1_Component_Property_Matrix.csv` records 105 individual
property findings across eight recommended candidates and two audited
alternatives, and names the analysis blocked by each unknown.

## Audit result

| Result | Count |
|---|---:|
| Existing BOM lines audited | 16 |
| COTS or configured COTS lines | 11 |
| Custom integration lines | 5 |
| Procurement-released lines | 0 |
| Lines with a current public firm price for the required configuration | 0 |
| Lines with a public indicative price | 1 (B01) |
| Lines with a current product/quote route verified | 12 of 16; five lines are custom rather than catalog products |

The hardware-only project estimate remains €29,350 low / €46,500 base / €70,100 high. These are quantity-extended planning estimates, not quotations. B01’s current storefront shows €3,450, €450 above its existing €3,000 base allowance. The controlled BOM has not been silently rebased.

No line is ready to purchase. B01 still lacks its exact switch/deployer configuration. B02 has a current product-page versus linked-datasheet battery-energy/configuration discrepancy. B03–B05 and B14 require signed custom panel designs. B06/B07 need current sales revisions and software/support scope. B08 now has a current manufacturer quote route and document set, but its option configuration is not selected. B09 needs authorized frequency and final mechanical/RF configuration. B10–B13 and B16 lack released drawings or complete bills of material. B15 lacks public electrical, shutter and protocol data and is inferior in documentation to candidate C01.

## Files

- [`component_audit.csv`](component_audit.csv) is the sortable master audit.
- [`cards/`](cards/) contains one engineering/procurement card for each existing BOM line.
- [`SOURCE_CHECK_LOG.md`](SOURCE_CHECK_LOG.md) records what was checked and distinguishes order routes from historical references.
- [`generate_component_cards.py`](generate_component_cards.py) reproducibly generates the CSV and all 16 cards from a fixed list matching B01–B16.
- [`Phase1_Functional_Audit.md`](Phase1_Functional_Audit.md) tests whether the required functions are covered.
- [`Phase1_Component_Property_Matrix.csv`](Phase1_Component_Property_Matrix.csv) records property-level evidence and gaps.
- [`candidates/`](candidates/) contains audited alternatives that have not changed the controlled BOM.
- [`Proposed_Operating_Component_Set.md`](Proposed_Operating_Component_Set.md) defines the complete 29-line flight-and-ground proposal and explains why it does not yet pass G1.
- [`Proposed_Operating_Component_Set.csv`](Proposed_Operating_Component_Set.csv) is the sortable component/gap register generated by `generate_proposed_operating_set.py`.
- [`operating_set_cards/`](operating_set_cards/) contains one traceable card for each of the 29 proposed flight and ground items.
- [`Custom_Component_Development_Register.md`](Custom_Component_Development_Register.md) defines the eight custom assemblies required to turn the COTS candidates into an operable system.
- [`phase1_closure/`](phase1_closure/) is the current consolidated review package. It expands the operating proposal to 52 flight, ground and support records, records actively checked alternatives, defines 25 custom work packages and performs a build-and-operate omission audit. It does not close G1.

Regenerate from the repository root with:

```powershell
python Components/generate_component_cards.py
```

## Evidence rules

- **VENDOR** means a current manufacturer page or registered manufacturer datasheet states the value. It does not establish that the delivered unit will have that revision.
- **PROJECT ALLOCATION/REQUIREMENT** means the project chose or budgeted the value. It is not a vendor guarantee.
- **CALCULATED** means the project calculation can be reproduced from stated inputs.
- **ASSUMPTION/PROVISIONAL** means the value only permits early layout or budgeting and cannot release hardware.
- **UNKNOWN** is preserved when the record does not support a value.

Order URLs point to a current product/quote/contact route when one was found. “Not applicable” is deliberate for custom hardware that cannot honestly be ordered until its engineering definition exists. Legacy PDFs are evidence references, not purchasing links.

No component has been purchased, received, inspected, measured, powered, environmentally tested, or independently expert-reviewed. This audit raises no item beyond DOCUMENTED/AUDITED status.

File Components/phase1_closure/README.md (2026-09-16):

# Phase 1 component evidence closure — review package

Revision A, 2026-09-15. **Partial closure; G1 remains open.**

Start with [the consolidated register](component_register.md). Its machine-readable companion is [component_register.json](component_register.json). This replaces the earlier 29-line operating proposal for review, without silently changing the controlled procurement BOM.

- [Alternative review](alternative_review.md): why candidates were retained, replaced or rejected.
- [Completeness audit](completeness_audit.md): mission coverage, omissions repaired and remaining build blockers.
- [Source index](source_index.md): exact manufacturer URLs, retrieval outcomes and hashes where original bytes were archived.
- `../../SOURCES/components/closure_2026-09-15/manifest.json`: original archive manifest. Manufacturer PDFs/HTML remain on the local drive; URLs/hashes are committed because redistribution rights are not established.

The register contains 52 records: 5 bounded component-level SUPPORTED records, 25 genuine custom work packages and 22 COTS/configuration exceptions. **No flight component is newly admitted; no integrated spacecraft is certified or shown viable.** A supported catalog part still needs installation/interface acceptance. Custom work packages are requirements and verification paths, not released schematics, drawings or constituent BOMs.

The requested all-SUPPORTED-or-CUSTOM final state is not achieved. Relabeling unsupported purchased assemblies as “custom” would undermine the Phase 1 rule. The exception state is deliberately preserved until evidence actually resolves it.

## Reproduce and check

From the repository root, using Python 3 standard library:

```text
python Components/phase1_closure/generate_register.py
python Components/phase1_closure/verify_register.py
```

The generator uses the preserved earlier operating-set CSV and the closure source manifest plus explicit reviewed revisions in the script. It produces the consolidated JSON, readable Markdown and source index. The script and inputs are versioned; generated JSON is the consolidated exchange format. Verification checks record IDs, source references, custom work-package coverage and archive hashes. It does not validate engineering adequacy or claim an independent review.

## Cost treatment

No purchases, subscriptions, cloud compute, professional services or tests were commissioned in this run. Incremental software/tool spend recorded: zero. AI subscription spend-to-date remains unknown until reconciled with the user's billing history; do not report it as zero. Existing hardware allowances remain estimates, not quotes. New exact ground proposals need delivered prices before a reliable complete cost total can be made.

Keep eight separate categories: AI; software/tools; spacecraft hardware; ground station; testing/verification; regulatory/licensing; launch/integration; external professional/expert review. Flight custom material/fabrication belongs to spacecraft hardware; test fixtures/instruments/calibration to testing; site hardware to ground station; human design/review labor to external expertise. Do not bury those costs in AI or double count bundled kit constituents.

No success-level increase, new CAD, simulation or performance claim accompanies this package. The Thermal Model Incident remains preserved and is not repaired by having a more complete parts list.

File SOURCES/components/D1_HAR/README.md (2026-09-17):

# D1-HAR-001 evidence archive

Retrieved 2026-09-17. This directory preserves the exact public evidence used
for the Revision-A harness material and RF cable selection.

| File | Identity | Source |
|---|---|---|
| `TE_Spec55_55A0111_drawing.pdf` | TE/Raychem 55A0111 product drawing | TE official document-delivery endpoint |
| `TE_Spec55A_product_specification.pdf` | TE Specification 55A, Issue 5, 2022-07-06 | TE official document-delivery endpoint |
| `Hirose_UFL_100mm_2D_drawing.pdf` | `UFL-2LPA-068Y2T-A-100` drawing 0001391668 | Hirose exact product page |
| `Hirose_UFL_100mm_specification.pdf` | `UFL-2LPA-068Y2T-A-100` specification 0001391666 | Hirose exact product page |
| `NASA-STD-8739.4A_change4.pdf` | NASA-STD-8739.4A with Change 4 | NASA Technical Standards System |
| `Western_Filament_A-A-52082_PTFE_lacing_page.html` | Manufacturer A-A-52082 PTFE lacing product page | https://wfilament.com/a-a-52082/ |

The official Molex PicoBlade specification and exact product records were
reviewed online. Repeated automated downloads from the manufacturer endpoint
timed out, so no local Molex file is claimed and no third-party copy is used as
primary evidence. The JST PA-family PDF is already preserved in `../D1_FAB/`.

Manufacturer material remains copyrighted local evidence. NASA material is
publicly accessible. None of these records is Degen-1 fabrication or test
evidence.

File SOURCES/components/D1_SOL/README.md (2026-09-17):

# D1-SOL-001 evidence archive

Retrieved 2026-09-17 from the public manufacturer source.

| File | Exact use | Evidence limit |
|---|---|---|
| `YAGEO_Nexensos_M222_Datasheet_EN.pdf` | Identifies YAGEO Nexensos M222 Pt1000 Class F 0.3 order number `32208571`; controls sensor dimensions, leads, electrical/thermal characteristics and catalog environmental data | Manufacturer explicitly does not recommend standard catalogue products for aerospace applications; mass, radiation/vacuum behavior and integrated panel performance are not established |

The file is copyrighted manufacturer material retained locally for evidence
custody. Its source URL, revision, retrieval date and SHA-256 are controlled in
`SOURCES/components/LOCAL_ARCHIVE_MANIFEST.csv`.

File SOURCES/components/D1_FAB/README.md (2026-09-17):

# D1-FAB-001 evidence archive

Retrieved 2026-09-17. This directory preserves the exact public files used for
the Revision-A launch-inhibit and front-access selection.

| File | Identity | Source |
|---|---|---|
| `BIRDS3-4_FAB_Schematic.pdf` | BIRDS-3/4 FAB schematic Rev 0.22 | BIRDSOpenSource/BIRDS4-FAB commit `efea2823d57298fe0f467f2fa06b1610dd27bc2c` |
| `BIRDS3-4_FAB_BOM.xlsx` | BIRDS-3/4 FAB BOM, revision history through 0.18 | same pinned repository |
| `BIRDS4_FAB_LICENSE_MIT.txt` | upstream MIT license | same pinned repository |
| `BIRDS4_FAB_UPSTREAM_README.md` | upstream project description | same pinned repository |
| `SameSky_SJ1-253X-SMT_datasheet.pdf` | current manufacturer jack drawing/specification, revision 1.07 | https://www.sameskydevices.com/product/resource/sj1-253x-smt.pdf |
| `SameSky_SP-2501_datasheet.pdf` | current manufacturer plug drawing/specification, revision 1.02 | https://www.sameskydevices.com/product/resource/sp-2501.pdf |
| `Vishay_SiA4265EDJ_datasheet.pdf` | manufacturer document 63162, Rev A | https://www.vishay.com/docs/63162/sia4265edj.pdf |
| `JST_PA_family_datasheet.pdf` | current JST PA-family specification/drawings | https://www.jst-mfg.com/product/pdf/eng/ePA-F.pdf |

The current Littelfuse/C&K SDS-series manufacturer PDF was reviewed at the
official asset endpoint but automated download returned a 403 response. Its
official URL and current revision are recorded in D1-FAB-001 and the source
register. A local file was not substituted from a similar switch.

The BIRDS files are retained under the upstream MIT license. Manufacturer PDFs
remain copyrighted local evidence. None of these records transfers flight
qualification or launch-provider acceptance to Degen-1.

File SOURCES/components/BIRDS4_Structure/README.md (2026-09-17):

# BIRDS-4 structure reference

Retrieved 2026-09-16 from the official `BIRDSOpenSource/BIRDS4-CAD`
repository at commit `3bab47a0f53410ef79005d21321ff659726f0a1c`.

This retained MIT-licensed subset contains the full flight-model STEP assembly,
the eleven unique frame-part STEP files used by that assembly, the upstream
README and the upstream license. The geometry is reference evidence and a
starting point for a Degen-1 derivative. It is not a Degen-1 released drawing,
material certificate, tolerance specification or structural qualification.

Upstream: https://github.com/BIRDSOpenSource/BIRDS4-CAD

The reproducible extraction script and its output are in
`drawings/freecad/structure_reference/`.

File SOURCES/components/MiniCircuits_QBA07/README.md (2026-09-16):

# Mini-Circuits QBA-07+ evidence

Retrieved 2026-09-16 from the manufacturer.

- Product: https://www.minicircuits.com/WebStore/dashboard.html?model=QBA-07%2B
- Datasheet: https://www.minicircuits.com/pdfs/QBA-07%2B.pdf

The copyrighted datasheet is retained locally for audit and omitted from the
public repository. Its byte count and SHA-256 hash remain in the manifest.

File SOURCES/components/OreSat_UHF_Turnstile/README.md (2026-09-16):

# OreSat UHF turnstile evidence

Retrieved 2026-09-16 from the official `oresat/oresat-antenna` repository at
commit `2f34667e775fc1f36366555dfce7e86039de1d9e`.

- `Canted_Turnstile_1.pdf` is the 2016-09-27 design and prototype-test record.
- `LICENSE_GPL-3.0.txt` is the upstream repository license.
- Upstream: https://github.com/oresat/oresat-antenna

This is upstream RF prototype evidence. It is not Degen-1 test evidence and it
does not define a flight deployment mechanism.

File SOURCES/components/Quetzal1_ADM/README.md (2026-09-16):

# Quetzal-1 antenna-deployment evidence

Retrieved 2026-09-16 from the official Quetzal-1 open-hardware repository at
commit `d4d1b59de384701a016a6e17353aff3c8ba64853`.

The retained subset contains the ADM README, reference BOM, schematic,
mechanical drawing, line-knot diagram and CC BY-SA 4.0 license. Upstream:
https://github.com/Quetzal-1-CubeSat-Team/quetzal1-hardware/tree/d4d1b59de384701a016a6e17353aff3c8ba64853/ADM

These are licensed upstream files. They document Quetzal-1 hardware and are not
Degen-1 fabrication data or Degen-1 test evidence.

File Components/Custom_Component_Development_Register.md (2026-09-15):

# D1-CMP-CUSTOM-001 — Required custom-component development register

Revision A · 2026-09-15  
Status: **REQUIREMENTS ALLOCATED / NO CUSTOM COMPONENT RELEASED**

These assemblies are required because the proposed operating set cannot be built
from the named major COTS units alone. A project part number identifies a design
task; it does not imply that geometry, materials or performance exist.

| Project part | Purpose | Minimum design record | Required analysis | Verification path | Current state |
|---|---|---|---|---|---|
| D1-IF-001 | Two protected, independently switched 3.3 V avionics rails plus a separately switched/current-limited camera branch; signal isolation and routing | Schematics, exact BOM, stack/harness pin map, PCB source/Gerbers, layout constraints, assembly drawing, firmware/register definition if any | Worst-case voltage/transient, startup/backfeed, open/short fault, thermal, EMC and radiation/SEE application analysis | Inspection, ICT, current-limit/fault injection, hot/cold functional, rail transient capture, EMC/radio coexistence, environmental test in integrated stack | DESIGN INCOMPLETE |
| D1-HAR-001 | Power, I2C, CAN, UART, inhibit, RBF and service wiring | Wire list, connector/contact part numbers, cavity map, gauges, lengths, shields, splices, labels, strain relief, workmanship and continuity table | Ampacity/derating, voltage drop, backfeed, grounding/EMC and bend/access review | Inspection, point-to-point/hipot as applicable, pull/retention, functional fault injection and post-environment continuity | DESIGN INCOMPLETE |
| D1-RF-001 | AX100-to-AntS 50-ohm interconnect | Exact coax and connector parts, length, routing, bend/retention drawing | Loss/VSWR and power margin over frequency/temperature | VNA insertion loss/return loss before and after environmental test | DESIGN INCOMPLETE |
| D1-CAM-MNT-001 | piCAM mounting, baffle, aperture and thermal/light isolation | Material/finish, drawing, tolerances, fasteners/locking, optical axis and keep-outs | Loads/margin, modal screen, thermal path, stray light and Sun-view risk | Dimensional inspection, alignment/FOV test, image test, vibration and thermal-vacuum functional test | DESIGN INCOMPLETE |
| D1-THM-001 | Measurable EPS/battery thermal interface and electrical isolation | Exact material part numbers, geometry, compression/fasteners, surfaces and installation process | Contact conductance range, electrical isolation, thermal balance and charge-limit control | Coupon/interface conductance measurement, insulation test, integrated thermal-balance/TVAC correlation | DESIGN INCOMPLETE |
| D1-MECH-HW-001 | Board retention, locking, brackets and conductive bonding | Itemized BOM, assembly drawing, torque/locking and surface-preparation schedule | Load path, fastener margin, bonding/grounding and mass properties | Receiving inspection, torque witness, bond resistance, fit check, vibration and post-test inspection | DESIGN INCOMPLETE |
| D1-GND-RF-001 | Installed ground feedline and RF protection path | Site length/routing, exact cable/connectors, weather seal, surge/T-R topology | Link loss, noise figure, transmit power, lightning/grounding and code review | VNA/loss/noise measurement, transmit interlock and weatherproofing inspection | DESIGN INCOMPLETE |
| D1-GND-SITE-001 | Antenna support, rotator mount, bonding, lightning and weather installation | Site survey, structural drawings, exact hardware, permits and grounding plan | Wind/ice/soil/foundation, lightning and electrical/code analysis | Professional/site review as applicable, inspection, pointing calibration and safe-motion test | DESIGN INCOMPLETE |

Every custom design must use exact constituent components with the same source,
revision, availability and property discipline as COTS subsystem selection. A
completed drawing without supporting analysis and verification does not pass G1.

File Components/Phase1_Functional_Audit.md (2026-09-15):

# D1-CMP-AUD-002 — Phase 1 functional component audit

Revision A · 2026-09-15  
Governing rule: `review/Phase1_Component_Evidence_Standard.md`

## Audit conclusion

The current documented spacecraft does **not** yet have a complete, publicly
fact-checkable component set. **No component is admitted to the Phase 1 baseline
by this audit.** Eight named COTS products remain the recommended candidate set,
and all are
`CANDIDATE / EVIDENCE INCOMPLETE` until a property-by-property applicability
matrix proves that every mission-relevant value is present in primary public
documentation. Five integration functions are unreleased custom designs or
allowances. The ground station is also incomplete.

This is an evidence finding, not a conclusion that the components will fail. It
means a claim that the spacecraft is presently functional would depend on
undocumented assumptions.

## Recommended Phase 1 candidate set

| Function | Candidate | Disposition | Reason |
|---|---|---|---|
| Structure | ISISPACE 1U, SKU 100000 | CANDIDATE / EVIDENCE INCOMPLETE | Current order route, but no public controlled mechanical package or mass |
| EPS/battery | ISISPACE ICEPS2 Type A | CANDIDATE / EVIDENCE INCOMPLETE | Strong public electrical data, but current capacity/configuration contradiction and missing installed thermal properties |
| Solar panels | ISISPACE customizable 1U family | CANDIDATE / EVIDENCE INCOMPLETE | Family is current; exact six-face configurations and IV/mechanical evidence are absent; Pumpkin C03 is an incomplete and currently unavailable alternative |
| OBC | GomSpace NanoMind A3200 | CANDIDATE / EVIDENCE INCOMPLETE | Good public data for preliminary work; exact delivery/software/fault evidence remains |
| Carrier | GomSpace NanoDock DMC-3 | CANDIDATE / EVIDENCE INCOMPLETE | Current order page plus datasheet, 2025 option sheet and qualification certificate; exact ordered configuration and certificate applicability must be established |
| Radio | GomSpace NanoCom AX100-U part 200315, Mode 5 | CANDIDATE / EVIDENCE INCOMPLETE | Current product, public datasheet and lifecycle PCN; exact firmware/manual, acceptance evidence and authorized frequency remain unresolved |
| Antenna | ISISPACE 1U–3U Turnstile, 5 V | CANDIDATE / EVIDENCE INCOMPLETE | Public family values exist; tuned configuration, commands, pattern and deployed geometry are not public |
| Camera | **SkyFox piCAM/FM** | **CANDIDATE / EVIDENCE INCOMPLETE** | Exact part, current €4,950 price/lead time and unusually complete 2025 datasheet; radiation, exact optical acceptance data and delivered-unit environmental evidence remain unresolved |
| Custom integration | D1-IF, harness, thermal interface, bracket/baffle and fasteners | CUSTOM COMPONENT REQUIRED / DESIGN INCOMPLETE | These are not purchasable components until detailed design creates constituent part numbers |

The property matrix also audits two Pumpkin alternatives. They do not replace
the recommended structure or panel candidates: the current selectable store
entries are marked unavailable, and mission-critical configuration data remain
missing.

The complete downstream physical proposal is now enumerated in
`Components/Proposed_Operating_Component_Set.md` and its generated CSV/cards.
That list covers all flight and ground hardware needed by the current concept;
it does not change any gate result in this audit.

## Changes from the previous audit

1. **Camera recommendation changed.** CrystalSpace CS-101 remains a real current
   product but public evidence gives only size, mass and pixel count. Power,
   supply, protocol, pinout, thermal limits and optics are critical and absent.
   SkyFox piCAM/FM supplies these publicly and directly matches the modest mission.
2. **DMC-3 availability finding corrected.** A current GomSpace product page was
   located. It links DS 1012962 rev 1.12, a 2025 option sheet and qualification
   certificate. B08 is a current quote-route candidate, not an unconfirmed legacy
   part.
3. **B12 is withdrawn as a component.** It is a mass/cost allowance with no
   manufacturer, material, part or geometry. It cannot supply thermal properties.
4. **The earlier 16-line audit was procurement-oriented rather than functional.**
   This audit adds the missing functional coverage test and shows that ground
   station and integration hardware are incomplete.

## Alternatives rejected during this pass

| Candidate | Result | Evidence reason |
|---|---|---|
| GomSpace NanoCam C1U | UNSUITABLE | Manufacturer product page states phased out/no longer available despite good documentation |
| CrystalSpace CS-101 | UNSUITABLE while piCAM/FM exists | Critical electrical, protocol, thermal and optical configuration data are not publicly available |
| GomSpace NanoPower P31u | UNSUITABLE | Manufacturer EOL notice made discontinuation effective 2025-10-01 |
| ISISPACE iOBC | UNSUITABLE as current reference | Storefront says out of stock; public technical brochure is old and supply tolerance is incomplete |
| EnduroSat current OBC/UHF/EPS | UNSUITABLE for this minimum-cost 1U baseline | Current OBC is 123 g/12 V, UHF radio 195 g with 1.2 W receive power, CubeSat EPS is USD 62k–75k, and current catalog no longer presents a 1U structure/panel line |
| ISISPACE TRXVU | CANDIDATE / EVIDENCE INCOMPLETE ALTERNATE only | Current storefront exists, but the detailed public brochure is legacy and exact current configuration/manual is not public |
| Pumpkin CubeSat Kit Rev D 1U skeletonized structure set | CANDIDATE / EVIDENCE INCOMPLETE ALTERNATE | Exact public assembly part numbers and CAD exist, but current selectable parts are marked unavailable; exact set mass, switch/end-plate configuration and qualification evidence are incomplete |
| Pumpkin fixed 1U solar-panel family | CANDIDATE / EVIDENCE INCOMPLETE ALTERNATE | Current family page gives thickness, price range and acceptance claims, but the selector is unavailable and exact configurations, mass, IV data, interfaces and environment limits are absent |

## Explicit evidence gaps and blocked analyses

- **ICEPS2 capacity/configuration:** 22.5 Wh current page versus 28.8 Wh in its
  linked issue 1.2 datasheet. This blocks a fact-based energy/life conclusion.
- **Thermal properties:** no selected thermal-interface hardware, installed
  conductance or component heat-capacity evidence. This blocks component-specific
  thermal prediction. TMI-001 applies.
- **Solar panels:** exact hot/cold/EOL IV curves and six mechanical layouts are
  absent. This blocks attitude/orbit power closure and camera-aperture feasibility.
- **3.3 V distribution:** public ICEPS2 output range and A3200/AX100/piCAM limits
  do not establish a safe integrated transient envelope. The unreleased D1-IF
  cannot close it. This blocks harness and fault-containment release.
- **Structure and deployment:** exact switch hardware, rails, fasteners and
  component-to-structure interfaces are absent. This blocks structural analysis.
- **Ground station:** the antenna alone is selected. End-to-end RF function is not
  established.

## Cost effect supported by public prices

Replacing the previous €6,000 base allowance for CS-101 with the listed
`piCAM/FM` price of €4,950 reduces the provisional flight-camera line by €1,050.
The €2,190 engineering model and €325 evaluation kit are separate development
costs and are not flight substitutes. No other quote-only component cost is
rebased. No hardware has been ordered.

## Required next engineering work

The next credible step is a **property-by-property evidence applicability matrix**
The property-by-property matrix is now established for the eight recommended
COTS candidates and two audited alternatives. Each row cites a document and
location or states `UNKNOWN`, then identifies the analysis prevented. Only a
candidate with no mission-relevant unknown may be proposed for the Phase 1
baseline. The next work is to close public evidence gaps where possible and
complete exact project configurations for configurable parts without ordering.

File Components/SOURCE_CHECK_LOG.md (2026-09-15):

# Component source and order-route check

Checked 2026-09-15. No supplier forms were submitted and no vendor was contacted.

| BOM lines | Source checked | Result for procurement |
|---|---|---|
| B01 | https://www.cubesatshop.com/product/1-unit-cubesat-structure/ | Current storefront listing shows €3,450, SKU 100000 and 4–6 weeks, with “Request more info.” Required configuration and mass are not published. Treat price/lead time as indicative. |
| B02 | https://www.isispace.nl/product/compact-electrical-power-system/ | Current Type A quote route. Page states 184 ±5 g, 96 × 92 × 26.45 mm and 22.5 Wh. Linked controlled-datasheet/configuration consistency must be resolved in the quote. |
| B03–B05, B14 | https://www.isispace.nl/product/small-satellite-solar-panels/ | Current configurable 1U product/quote route. No public price. Configuration-specific drawings and guaranteed performance are required. |
| B06 | https://gomspace.com/product/nanomind-a3200/ | Current product/contact page and downloadable older datasheet. No public price or lead time. |
| B07 | https://gomspace.com/product/nanocom-ax100/ | Current product/add-to-quote page. AX100-U and Mode 5 details must be tied to the delivered revision and S11 PCN. |
| B08 | https://gomspace.com/product/nanodock-dmc-3/ and S45–S47 | Current manufacturer page offers Add to quote and links DS 1012962 rev 1.12, OSF 1012964 rev 2.3 dated 2025-04-14 and qualification certificate 1028503 for product 200232. Exact option selection, price, lead time and delivered revision remain open. |
| B09 | https://www.isispace.nl/product/vhf-uhf-antenna-for-1u-3u/ | Current selectable Turnstile product/quote route. Exact 5 V UHF configuration, frequency and mechanical interface require quote. |
| B10 | https://www.ti.com/product/TPSM82823 | Candidate regulator is listed active/orderable by TI. B10 itself is an unreleased custom assembly and cannot be ordered from this link. |
| B11–B13, B16 | Project engineering record only | Custom integration lots have no supplier or order URL because drawings/specifications are not released. |
| B15 | https://crystalspace.eu/products/cs-101-kikas/ | Current product/contact page confirms 42 × 25 × 45 mm, 50 g and 5 MP. Detailed brief and quote require contact; public electrical data remain unavailable. It is unsuitable for Phase 1 while the better documented SkyFox piCAM/FM candidate exists. |
| C01 candidate | https://www.skyfoxlabs.com/product/27-picam and S49 | piCAM/FM exact variant, €4,950 single-unit price, 2–4 week lead time and a public 2025 datasheet with pinout, commands, mechanics, limits and integration guidance. Mission-relevant radiation, optical acceptance, peak/startup and configuration-specific environmental evidence remain incomplete, so it is not admitted to the baseline. |
| C02 alternative | S53–S57 | Pumpkin publishes exact Rev D 1U skeletonized structure component numbers and public assembly CAD, plus material/finish and interface guidance. Current store selectors are marked unavailable, and exact-set mass, selected switch/end-plate configuration and qualification evidence are incomplete. |
| C03 alternative | S58–S59 | Pumpkin's current fixed-panel family page gives 0.8 mm thickness, a USD 2,500–5,650 range and per-panel bakeout/irradiance claims. Current selections are marked unavailable and exact configuration, mass, IV curves, harness and environmental data are absent. |

## Registered detailed sources

The component cards refer to IDs in `review/Source_Register.md`. Component evidence added in this pass is S44–S59. This log records the procurement audit and does not duplicate or replace that controlled register.

## Price handling

Public prices are transcribed with their original currency and date. No foreign-exchange conversion is inferred. Vendor-quote items retain the low/base/high EUR planning allowances from `procurement/BOM.csv`. A future received quotation must record exact configuration, currency, validity, taxes, freight, duties, NRE, software/support, test scope and delivery terms before updating the controlled cost baseline.

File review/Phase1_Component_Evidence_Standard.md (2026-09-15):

# D1-CMP-STD-001 — Phase 1 component evidence standard

Revision A · 2026-09-15

## Purpose

Phase 1 prefers a component whose critical behavior can be checked from public
manufacturer evidence over a nominally better component that requires hidden
assumptions. This standard applies before a part is called a Phase 1 reference
component. It does not constitute procurement release, qualification or flight
approval.

## Phase 1 Component Evidence Requirement

Every physical component selected for the Phase 1 spacecraft baseline must
correspond to an identifiable, commercially obtainable part or an explicitly
documented custom-fabricated part.

Every selected COTS component must have publicly accessible, independently
verifiable manufacturer technical documentation sufficient to establish the
properties relevant to its use in DEGENERATE-1. A manufacturer datasheet, ICD,
user manual, mechanical drawing, qualification report or equivalent primary
document is acceptable only when its actual contents establish the needed
property. The existence of a document or product page is not evidence that an
unstated property is known.

At minimum, the evidence set must establish, as applicable: exact manufacturer
and part number/configuration; dimensions and mass; electrical interfaces;
supply voltage, current and power in all relevant modes; communications
interfaces and protocols; connector and pinout information; operating, storage
and thermal limits; mechanical interfaces; and deployment or operational
constraints. Mission life, environment and safety properties are required when
they are needed to analyze the assigned function.

Missing required data may not be replaced with generic values, a similar
product's values or AI-generated assumptions to pass this gate.

## Selection states

- **PHASE 1 BASELINE** — exact obtainable COTS configuration or released custom
  design; public primary evidence establishes every property needed for its
  assigned mission function. Configuration-controlled as-built and physical test
  evidence can remain later verification work, but no missing property may be
  silently assumed.
- **CANDIDATE / EVIDENCE INCOMPLETE** — a plausible part, but one or more required
  properties cannot be independently verified. It cannot enter the Phase 1
  baseline. It may remain in trade studies or envelope-only CAD when the evidence
  limitation is displayed with it.
- **UNSUITABLE** — current evidence or availability contradicts the mission, or a
  critical behavior cannot be established and a better documented alternative
  exists.
- **NO DOCUMENTED ALTERNATIVE** — critical property is absent and no better public
  option was found. The function requires a custom component or remains an open
  architecture function; do not simulate the gap.
- **CUSTOM DESIGN** — integration hardware that cannot honestly be represented as
  a purchased COTS subsystem. It needs a released design, constituent BOM and test.

## Minimum evidence gate

Every COTS selection needs:

1. manufacturer and exact public product/part identifier;
2. current manufacturer product or order/quote route and access date;
3. mechanical envelope, mass, mounting/interface drawing and keep-outs needed now;
4. input voltage range, current/power by relevant mode, startup/transient limits
   and output ratings where applicable;
5. named connector, pinout, signal levels and data/protocol information sufficient
   to design and test the interface;
6. operating and storage temperature limits distinguished from qualification;
7. public environmental, workmanship, radiation and heritage claims recorded
   exactly with their scope and revision;
8. software/firmware/API availability for commanded devices;
9. price or explicit `QUOTE REQUIRED`, lead time if published, configuration and
   export restrictions;
10. contradiction check among the current page, datasheet, option sheet, PCN and
    project record.

The gate is function-specific. A passive carrier may not require operating power;
a battery requires cell configuration, charge/discharge limits, protection and
life evidence; a camera requires optics, exposure/image behavior and data transfer;
an antenna requires RF and deployment behavior.

## Missing-property rule

Do not fill a missing critical property with a generic value. Record:

`PROPERTY UNKNOWN -> SOURCE(S) CHECKED -> ANALYSIS BLOCKED -> REQUIRED EVIDENCE`

An assumption may support a clearly labeled geometric envelope or sensitivity
study only when its result cannot be mistaken for component behavior. It may not
pass or fail a requirement, update a hardware readiness level, or become a
procurement specification without an explicit project decision and verification
method.

## Document custody

Each component source pack contains official URLs, document identifiers,
revision/date, retrieval date, evidence classification, project-authored fact
extraction and SHA-256 for any locally retained file. Archived copies are
preserved only where licensing permits. A downloaded file whose license does not
permit redistribution remains local and excluded from the public repository; the
repository keeps its official URL, identity and hash so another reviewer can
retrieve and compare the exact source.

## Evidence ceiling

Public documentation can support DOCUMENTED, CALCULATED and MODELED work. A
catalog claim of qualification or heritage is attributed to the manufacturer and
does not prove the ordered unit, integrated spacecraft, launch survival or one-year
operation. Those require configuration records, inspection, analysis, physical
test and independent review appropriate to the claim.

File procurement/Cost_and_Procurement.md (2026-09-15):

# D1-CST-001 — Cost estimate and procurement strategy

Revision A | EUR planning allowances; 2026-09-14. No arbitrary spending ceiling is imposed.

## Cost result

Flight hardware has a EUR29,350 low scenario, EUR46,500 base and EUR70,100 high scenario. The **realistic minimum-cost planning case for spacecraft build is about EUR81,350**, including engineering hardware, assembly and engineering labor. Base spacecraft build is EUR152,500. These estimates assume an experienced small team and substantial reuse; they are not a promise that the lowest scenario can be purchased. Hardware-only price omits the work needed to make the satellite fly.

| Separate cost category | Low EUR | Base EUR | High EUR |
|---|---:|---:|---:|
| Spacecraft build: flight hardware | 29,350 | 46,500 | 70,100 |
| Spacecraft build: engineering hardware/spares | 8,000 | 18,000 | 30,000 |
| Spacecraft build: assembly/workmanship labor | 4,000 | 8,000 | 16,000 |
| Spacecraft build: nonrecurring engineering labor | 40,000 | 80,000 | 180,000 |
| Testing: external facilities and campaign support | 15,000 | 35,000 | 75,000 |
| Ground station: equipment and installation | 4,000 | 12,000 | 25,000 |
| Licensing/coordination: professional support and filing allowance | 5,000 | 15,000 | 40,000 |
| Launch: rideshare/deployer/integration service | 40,000 | 65,000 | 120,000 |
| Operations: 12 months recurring support | 5,000 | 12,000 | 30,000 |
| **Spacecraft build subtotal, first four rows only** | **81,350** | **152,500** | **296,100** |
| **All categories subtotal, do not add build subtotal again** | **150,350** | **291,500** | **586,100** |

Add 25% program contingency as a planning reserve: total authorization envelope about EUR187,938 / EUR364,375 / EUR732,625. Contingency is not a hidden markup on each BOM line. Taxes, duties, exchange-rate movement, major launch delay/reflight, insurance, extensive dedicated radiation qualification and new ground-site civil works are excluded. A targeted-imaging mission with ADCS is outside scope.

The NRE allowance can be read as roughly 800 hours at EUR50/h in the unusually lean case, 1000 hours at EUR80/h base, and 1800 hours at EUR100/h high; these are explicit project assumptions, not surveyed market rates. If this is a first-time team or the adapter/camera needs major qualification, those hours may be insufficient. No donated labor is silently assumed in the build subtotal.

## Price evidence versus estimates

Every selected flight item is presently budgeted using an engineering allowance. Vendors mostly require a quote. Published current comparison prices include EXA KRATOS EUR44,000–155,000 [S19], Crystalspace P1U EUR4,400 [S20], and M2 ground antenna USD910.95 [S29]. They are different configurations and currencies and are not inserted into the EUR BOM as firm quotes. No FX conversion is claimed. Competitive quotations should be normalized to delivery date, taxes, freight, software, support and acceptance-test scope.

The 2026-09-15 launch/deployer gate found SpaceX's published direct rideshare
entry price of USD350,000 for a 50 kg SSO plate plus USD7,000 per additional
kilogram [S34]. That is not a 1U launch quote and does not validate or replace
the EUR40,000–120,000 integrator allowance above. EXOLAUNCH and ISISPACE publish
inquiry routes but no complete 1U price, orbit, schedule or included-service
scope. The launch/integration line remains an unverified project estimate until
comparable written offers are authorized and received.

## Hardware alternatives

| Candidate | Rationale | Decision / required evidence |
|---|---|---|
| Selected mixed COTS subsystem baseline | Small low-power avionics, six-face energy recovery, compact flight-oriented camera | Conditional; adapter/ICDs and DMC supply are key risks |
| Basic EXA KRATOS 1U plus camera | May eliminate inter-vendor integration and some test/NRE work | RFQ against same image, lifetime, orbit and compliance requirements; advertised entry price not assumed to include chosen camera |
| Alen 1U platform plus camera | Turnkey bus potentially reduces software and AIV | Quote with acceptance reports and image integration [S21] |
| CrystalSpace EPS substitution | Lower published entry EPS price | Do not substitute until battery/solar/inhibit/environment interfaces close |
| Consumer camera and custom MCU/radio stack | Cheapest raw parts | Substantial development/qualification; no twelve-month evidence or cost advantage established |
| Five-panel bus or active-pointing imager | Fewer panels saves parts / pointing improves targeting | Five-panel fixed-attitude recovery loses geometric guarantee; ADCS adds cost and qualification |

There is no proof of global minimum cost without actual comparable offers. The procurement rule is minimum **total cost of compliant delivery**, including one-time engineering, test gaps and expected retest exposure. All catalog availability claims require written lead-time and supported-revision confirmation. In particular DMC-3 has an older indexed primary datasheet with a dead direct URL; do not treat it as confirmed in-stock hardware.

## Request-for-quotation package (draft; not sent)

Provide these documents to candidate bus and subsystem suppliers and request:

1. Firm exact part/configuration numbers, current hardware and software revisions, obsolescence status, lead time, Incoterms, validity, payment terms, warranty and export classification.
2. As-ordered mass/STEP models, mechanical drawings, electrical pin maps, input/output tolerances, peak/idle currents, memory map and command protocols; include every adapter/harness and flight-software license needed.
3. Mission suitability evidence for one year at 450–500 km, delivered-lot radiation/SEE evidence, battery cycle/calendar evidence and environmental qualification/acceptance reports with actual profiles.
4. Three-inhibit/RBF configuration, isolation of solar/battery/debug power, cold battery restart and end-of-life source passivation. Request a system-level fault-tree review of inhibit independence.
5. Five >=2.3 W panels plus one >=1.8 W camera-aperture panel, cell string layout, hot/cold IV curves and AntS top mounting. Request guaranteed startup/MPPT compatibility.
6. CS-101 lens/FOV, supply, power, interface, shutter, JPEG/reduced-resolution support, Sun exposure and thermal focus data. Quote camera and aperture integration separately.
7. Ground modem/waveform compatibility and measured Mode 5 sensitivity; supported CAN settings and rate. Confirm operating band only after licensing review.
8. Separate flight hardware, engineering units, NRE, assembly, testing, ground support and launch services. Identify provided acceptance tests so facility costs are not double counted.

No purchases, external messages or license filings have been made. Firm supplier and launch quotes are the next evidence needed to convert this estimate into a purchasing baseline.
## AI and software cost boundary

The project baseline is ChatGPT Plus at $20/month, with Codex/Astra where available, and free/open-source engineering tools wherever practical. Enterprise AI, specialist AI platforms, large API usage and paid cloud compute are not assumed. The [Project Cost Ledger](Project_Cost_Ledger.csv) keeps AI/tooling separate from physical mission costs. External expert review and physical verification are separate human/test costs.

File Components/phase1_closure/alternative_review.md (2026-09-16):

# Alternatives reviewed and disposition

2026-09-15 — public-document review only. No quotations, vendor contacts, purchases, new CAD or simulations. References E## resolve in `source_index.md`. Retained candidates are not retained as an approved baseline; each remains replaceable.

| Function | Alternatives actively checked | Result and selection consequence |
|---|---|---|
| Structure | Existing ISISPACE SKU 100000; Spacemanic 1U structure E05 | Spacemanic publishes 100 × 100 × 113.5 mm, 115 g and supplied assembly hardware. This is better dimensional evidence than an allocation, but not a controlled drawing/tolerance/finish/load qualification set. Its two switches do not establish the project's independent inhibit implementation. Keep both unadmitted; do not claim either frame fits EXOpod as ordered. |
| Power conversion and distribution | ICEPS2; Spacemanic Amun E02/E25/E35; AAC Starbuck Nano E10; GomSpace P31u E06 | Amun's older 5.1 manual provides connector/pin information and identifies the cell; current 5.3 bytes were inaccessible. It requires a ground-service reset to turn off after its inhibit inputs are deactivated, a major safety-interface issue. Public output regulation/command detail still does not close the interface. Starbuck's summary sheet lacks the needed detailed interfaces/configuration. P31u end-of-life notice makes availability unsuitable for a new reference selection without stock/lifecycle evidence. No fully supported replacement found. |
| Battery | ICEPS2 integrated pack; Amun NCR18650B-based pack E25; AAC Optimus E11 | Knowing the Amun cell name is useful, but installed protection, thermal path, charge behavior and usable life still need evidence for the actual assembly. Optimus family information does not establish an exact configured 1U-compatible pack and pinout. ICEPS2's 22.5/28.8 Wh conflict remains unresolved. Do not analyze a generic lithium-ion battery. |
| Solar generation | Existing configured ISISPACE panels; Spacemanic Ra E04/E38; GomSpace P110 E09; AZUR 3G30 Advanced E22; Spectrolab UTJ CIC E23 | Ra has a public sheet and current page, but mass/revision and exact face configuration remain unresolved. P110's attempted legacy source failed. AZUR's documented 6 × 12 cm cell does not fit the intended 1U face as a flat cell; do not resize it in CAD. Spectrolab's family sheet does not specify an orderable face panel/coverglass/interconnect configuration. Custom face integration is explicit; cell IV/environment properties remain blockers, not generic inputs. |
| OBC/storage/sensors | NanoMind A3200; Spacemanic Eddie E01/E24/E34 | Eddie's older 3.1 manual provides connector/mount details and a public firmware-example reference, but current 3.2 was not obtained. Its MCU identity differs between paragraph and table. Its listed FRAM arrangement is not equivalent to A3200's 128 MB image-store allocation. No capacity/performance equivalence assumed. A3200 remains the stronger current architecture match, still unadmitted for revision/software/recovery/environment evidence. |
| Flight/ground radio | AX100-U Mode 5; Spacemanic Murgas E03/E36 | Murgas 3.1 specifies several bands, 67 × 42 × 7.5 mm, 25 g, 3.3 V plus CAN 5 V, receive/transmit power, RF and digital connector details. Its software section directs development support to the manufacturer; CSP/AX.25 names alone do not supply its command dictionary. It would change both carrier and ground waveform integration. It is a credible challenger, not an independently implementable drop-in replacement. |
| Deployable antenna | ISISPACE AntS; Spacemanic SAM-S E26/E37; GomSpace ANT430 E07/E08 | Propose SAM-S instead of the AntS family because its reviewed revision supplies materially better connector/pinout and mechanical detail. It remains CANDIDATE: tuned order configuration, complete commands, deployed envelope/pattern and application evidence are not closed. Original-byte retrieval failed. ANT430 legacy sources failed. Update the proposed panel and coax interfaces; do not change existing CAD. |
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

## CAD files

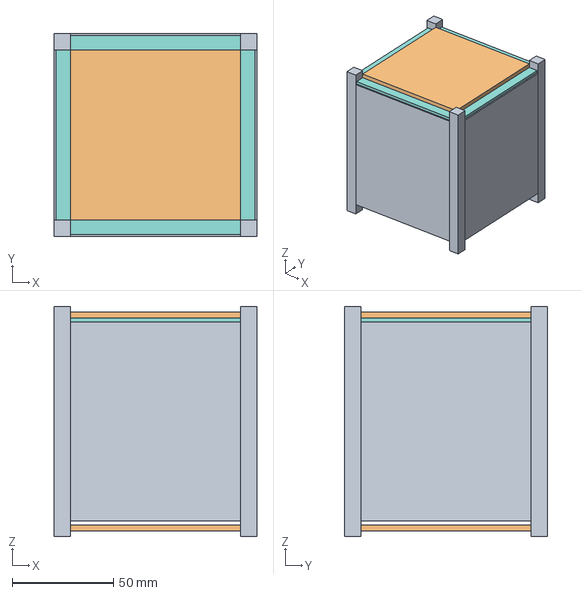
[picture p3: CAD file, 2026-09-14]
drawings/freecad/exports/Degen1_CAD001_envelopes.step
100.0 x 100.0 x 113.5 mm

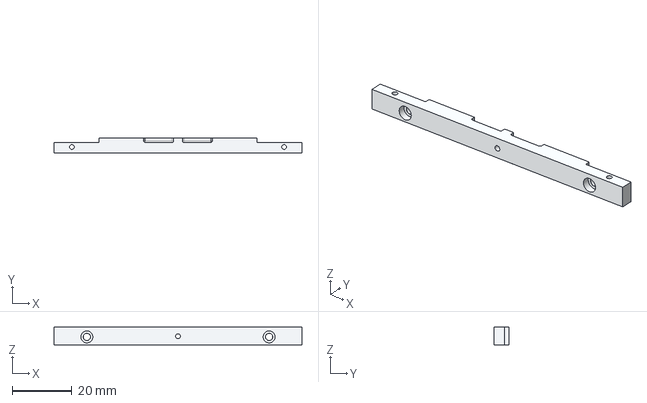
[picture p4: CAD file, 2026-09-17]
SOURCES/components/BIRDS4_Structure/B4_frame2S v15.step
83.0 x 5.00 x 5.90 mm

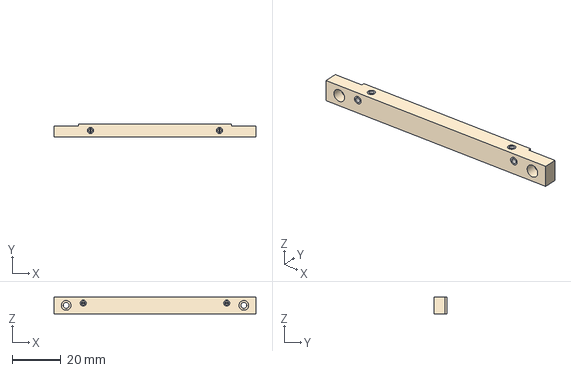
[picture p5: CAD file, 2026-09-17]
SOURCES/components/BIRDS4_Structure/B4_frame3 v15.step
83.0 x 5.50 x 6.90 mm
HLTS4_4 x 4

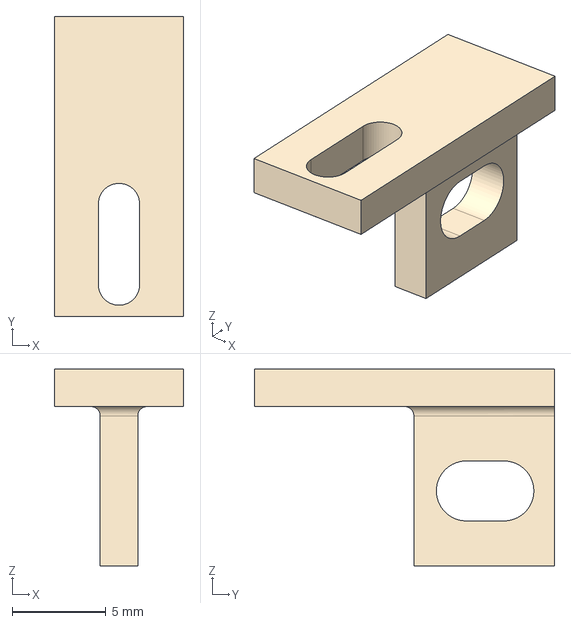
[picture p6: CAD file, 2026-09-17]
SOURCES/components/BIRDS4_Structure/B4_frame4 v8.step
6.90 x 16.0 x 10.5 mm

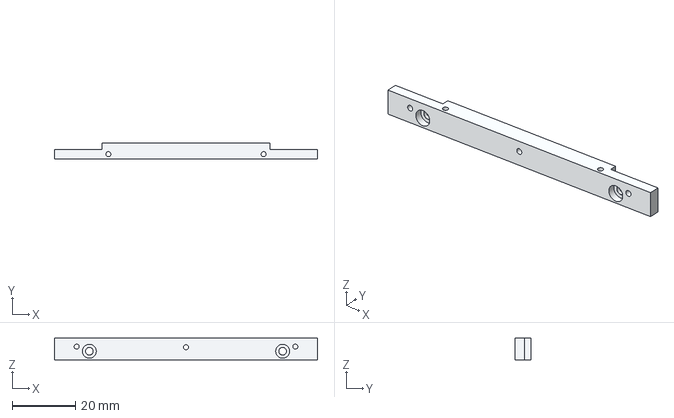
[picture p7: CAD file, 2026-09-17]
SOURCES/components/BIRDS4_Structure/B4_frame2 v6.step
83.0 x 5.00 x 6.90 mm

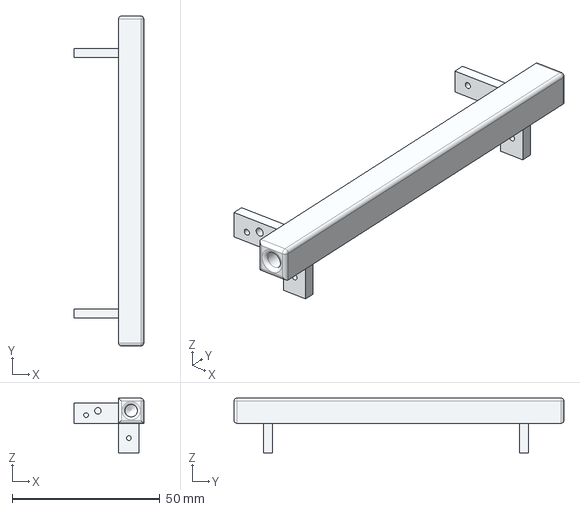
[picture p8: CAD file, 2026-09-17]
SOURCES/components/BIRDS4_Structure/B4_frame6Y v15.step
23.5 x 111.5 x 18.5 mm

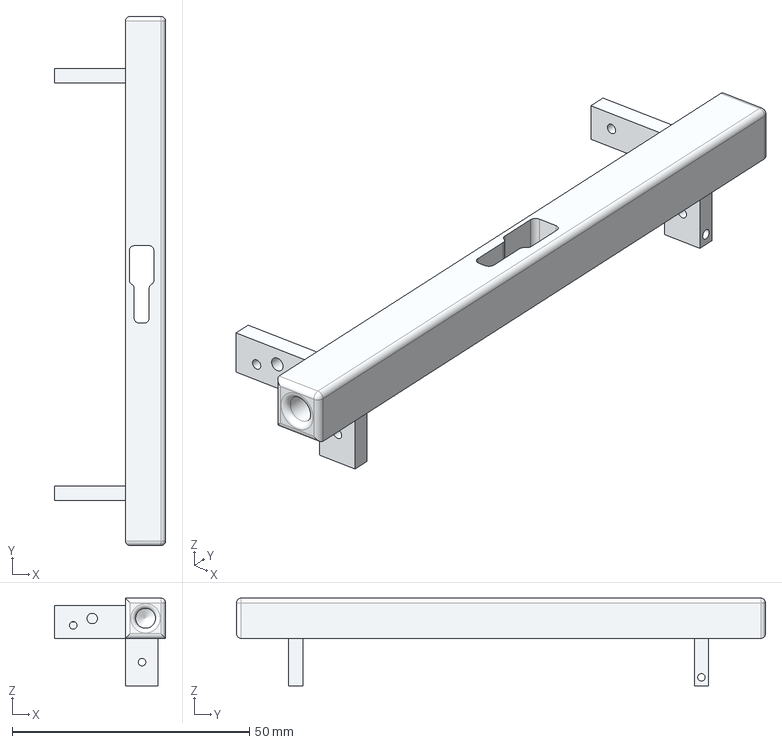
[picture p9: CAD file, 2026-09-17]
SOURCES/components/BIRDS4_Structure/B4_EM_frame6X v14.step
23.5 x 111.5 x 18.5 mm

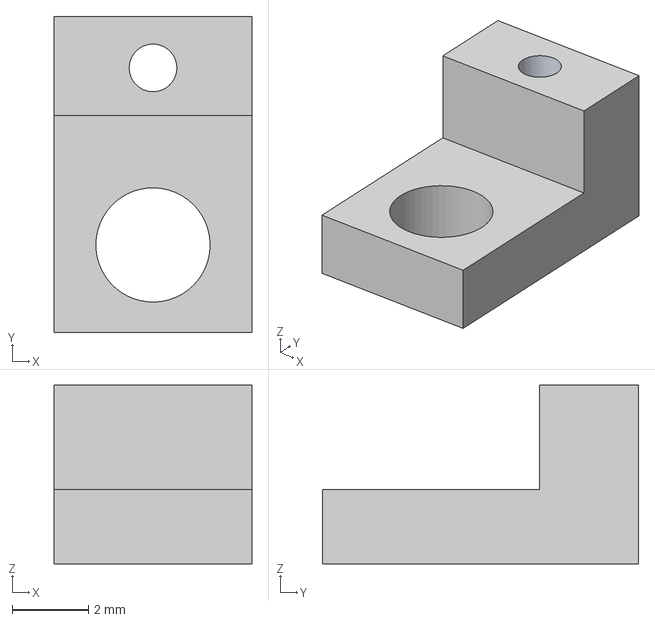
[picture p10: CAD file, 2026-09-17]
SOURCES/components/BIRDS4_Structure/B4_frame7_updated_after_FM v2.step
5.20 x 8.30 x 4.70 mm

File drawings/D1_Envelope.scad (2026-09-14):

// Degen-1 Rev A: visual allocation only. Units mm. NOT manufacturing CAD.
// Origin at nominal geometric center; camera optical axis +X.
module box(lo,hi,col){color(col)translate([0,0,(lo+hi)/2])cube([88,88,hi-lo],center=true);}
color([.4,.45,.5])for(x=[-46,46])for(y=[-46,46])translate([x,y,0])cube([8,8,113.5],center=true);
box(-21,-15,[.7,.5,.8]); // adapter envelope
box(-12,14.5,[.4,.7,.6]); // EPS/battery envelope
box(20,36,[.4,.6,.85]); // carrier and top-side avionics allocation
box(44,51,[.7,.75,.8]); // AntS allocation, not actual mechanism
color([.9,.65,.3])translate([25,0,-35.5])cube([45,42,25],center=true);
// Six panel placeholders omitted where they obscure internal view.

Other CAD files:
drawings/freecad/exports/Degen1_CAD001.FCStd
SOURCES/components/BIRDS4_Structure/B4_frame1F v12.step
SOURCES/components/BIRDS4_Structure/B4_frame1 v6.step
SOURCES/components/BIRDS4_Structure/B4_frame5B v14.step
SOURCES/components/BIRDS4_Structure/B4_frame5A v29.step

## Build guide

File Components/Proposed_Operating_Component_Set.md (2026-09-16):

# D1-CMP-SET-001 — Complete proposed operating component set

Revision 0 · 2026-09-15  
Status: **SUPERSEDED HISTORICAL PROPOSAL / NOT PHASE 1 BASELINE / NOT PROCUREMENT-RELEASED**

This file preserves the 2026-09-15 mixed ISISPACE/GomSpace proposal and its
evidence gaps. D1-TRD-ARCH-001 subsequently rejected that combination as the
design-development baseline. The active design is controlled by
`Components/design_baseline/README.md` and `COMPLETENESS_MATRIX.md`.

## Decision

The smallest currently supportable Degen-1 operating architecture comprises 19
flight-hardware lines and 10 ground-segment lines. It retains the documented 1U,
uncontrolled-attitude imaging concept and adds the integration and ground items
that the original major-board BOM omitted.

This proposal does **not** meet the Phase 1 evidence requirement as a set. No row
is marked `PHASE 1 BASELINE`. The project cannot truthfully state that a complete
requirements-compliant, publicly verifiable set has been found. The value of this
document is that every required physical function now has either:

- a named COTS candidate;
- an explicit project custom-component identifier; or
- `NO COMPLIANT PART IDENTIFIED`.

The sortable controlled detail is
`Components/Proposed_Operating_Component_Set.csv`, generated by
`Components/generate_proposed_operating_set.py`.

## Proposed flight set

| ID | Function | Proposed component | Quantity | Phase 1 result |
|---|---|---|---:|---|
| FLT-001 | Structure/rails | ISISPACE 1U structure, SKU 100000 | 1 | Evidence incomplete |
| FLT-002 | Separation inhibits and RBF | ICEPS2 three-switch/RBF option plus structure actuators | 1 configured set | No documented exact implementation |
| FLT-003/004 | EPS and battery | ISISPACE ICEPS2 Type A integrated assembly | 1 | Evidence incomplete; capacity/configuration conflict |
| FLT-005–008 | Six fixed solar faces | ISISPACE customizable 1U two-cell family: three ordinary sides, -Z switch relief, +Z AntS interface, +X camera aperture | 6 panels | Exact configurations and IV/mechanical evidence incomplete |
| FLT-009 | OBC/storage/RTC/watchdog/rate sensing | GomSpace NanoMind A3200 | 1 | Evidence incomplete |
| FLT-010 | OBC/radio carrier | GomSpace NanoDock DMC-3, product 200232 | 1 | Evidence incomplete until D1-IF/harness pin map permits option selection |
| FLT-011 | UHF modem | GomSpace NanoCom AX100-U, part 200315, Mode 5 | 1 | Evidence incomplete |
| FLT-012 | Deployable antenna | ISISPACE AntS 1U–3U, UHF turnstile, 5 V | 1 | Exact order configuration incomplete |
| FLT-013 | Earth camera | SkyFox Labs piCAM/FM | 1 | Best documented camera candidate; evidence incomplete |
| FLT-014 | Protected 3.3 V distribution/interface | Custom D1-IF-001 | 1 | Design incomplete |
| FLT-015 | Power/data/inhibit harness | Custom D1-HAR-001 | 1 | Design incomplete |
| FLT-016 | Flight RF coax | Custom D1-RF-001 | 1 | Design incomplete |
| FLT-017 | Camera bracket/baffle | Custom D1-CAM-MNT-001 | 1 | Design incomplete |
| FLT-018 | Battery thermal interface | Custom D1-THM-001 | 1 | Design incomplete |
| FLT-019 | Mounting/locking/bonding hardware | Custom D1-MECH-HW-001 itemized kit | 1 | Design incomplete |

The architecture intentionally has no propulsion, reaction wheels, GNSS
receiver, deployable solar array or precision-pointing subsystem. A3200 rate
sensing supports image-timing/tumble screening; it does not provide pointing.
Ground-derived orbit data and opportunistic imaging satisfy the current mission
concept only if later analysis and testing demonstrate an adequate image
opportunity.

## Proposed ground set

| ID | Function | Proposed component | Phase 1 result |
|---|---|---|---|
| GND-001 | Matching Mode 5 modem | Second AX100-U, part 200315 | Evidence incomplete for ground firmware/API |
| GND-002 | Ground modem carrier/USB | Second DMC-3, product 200232 | Exact ground option set incomplete |
| GND-003 | Protected modem supply | No compliant exact part identified | Blocked by carrier/power interface |
| GND-004 | Circularly polarized antenna | M2 436CP42UG | Evidence incomplete pending frequency/site/feed system |
| GND-005 | Az/el tracking | No compliant exact rotator/controller identified | Open selection |
| GND-006 | Outdoor RF feedline | Custom D1-GND-RF-001 | Site design incomplete |
| GND-007 | Filter/LNA/T-R routing | No compliant exact chain identified | Open selection |
| GND-008 | Mast/lightning/grounding | Custom D1-GND-SITE-001 | Site design incomplete |
| GND-009 | Station computer | No compliant exact part identified | Ground software/interface requirements incomplete |
| GND-010 | Final image printer | No compliant exact part identified | Print/interface requirements incomplete |

The second AX100 avoids claiming that an undocumented third-party SDR can produce
or decode GomSpace Mode 5. It is a candidate only; public material has not yet
established a complete supported ground-modem configuration.

## Functional architecture

```text
6 fixed panel configurations
        -> ICEPS2 Type A + integrated battery
        -> three physical separation/inhibit paths + RBF
        -> D1-IF-001 protected 3.3 V OBC branch -> A3200
        -> D1-IF-001 protected 3.3 V radio branch -> AX100-U
        -> switched 3.3 V payload branch -> piCAM/FM -> UART -> A3200
        -> switched 5 V deployment branch -> AntS

A3200 <-> CAN/CSP <-> AX100-U -> D1-RF-001 -> AntS
A3200 <-> I2C <-> ICEPS2
A3200 <-> isolated I2C <-> AntS

AntS <-> M2 436CP42UG + rotator/feed/filter chain
      <-> ground AX100-U/DMC-3 <-> station computer
      -> reconstructed image -> printer
```

## Preliminary resource effect

Substituting piCAM/FM's documented 40 g for the old 50 g CS-101 allocation makes
the flight-set planning mass 1,053.5 g before growth, or 1,264.2 g with a uniform
20% growth factor. This is a bookkeeping calculation, not a CAD mass or measured
mass. It remains below the project's 1,330 g target on paper.

The same substitution changes the existing hardware planning midpoint from
EUR 46,500 to EUR 45,450. This is not a quote and excludes the incomplete ground
chain, engineering/prototype hardware, tests, licensing, launch and integration.
No procurement baseline is changed by this calculation.

## Gate result and next action

The proposal is functionally complete as a list but fails G1 because its evidence
and custom designs are incomplete. The first closure package remains FLT-001 and
FLT-002: structure, rails, exact separation-switch hardware and RBF/source
isolation. Until that package passes, the mechanical foundation and launch-safety
architecture are not fixed.

Do not promote this document by deleting the gaps. Close them with exact public
evidence or record the point where later supplier evidence, professional review or
physical test becomes necessary.

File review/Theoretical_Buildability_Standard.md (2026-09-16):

# D1-DES-STD-001 — Education-grade theoretical buildability standard

Revision A · 2026-09-16  
Status: **CONTROLLING DESIGN COMPLETION STANDARD**

## Purpose

DEGENERATE-1 reaches the current project's design goal when an aerospace
engineering student or engineer can independently audit a coherent, theoretically
viable spacecraft and ground-station design using the repository and its cited
public evidence. Purchasing, fabrication, physical testing, qualification,
licensing and launch-provider acceptance are later implementation and validation
stages. They are not prerequisites for completing this theoretical design.

This standard does not relax evidence discipline. A polished drawing, calculation
or AI assertion is not physical proof. The final package must identify each claim
as DOCUMENTED, PROJECT DECISION, CALCULATED, MODELED, SIMULATED, TESTED or
EXPERT-REVIEWED. Untested work remains untested.

## Design-complete exit criteria

The education-grade theoretical design is complete only when:

1. the mission and operating concept are fixed and every required function maps
   to an exact, commercially identifiable part or a released custom design;
2. every selected COTS part has a manufacturer, exact model/configuration,
   order or quote route and primary technical documentation sufficient for the
   properties used in the design;
3. every custom item has requirements, a schematic or dimensioned drawing as
   applicable, exact constituent BOM, interfaces, material/process notes,
   assembly instructions and a verification plan with acceptance criteria;
4. electrical, data, RF and mechanical interfaces are reconciled pin-to-pin or
   feature-to-feature, including connectors, contacts, cables, fasteners,
   clearances, inhibits, service access and fault-safe states;
5. mass, center of mass, power, energy, data storage, communications, thermal,
   structural screening, orbit/debris and cost budgets are reproducible from the
   selected parts and explicit calculations, with uncertainty and margin;
6. the spacecraft fits its stated 1U/deployer reference in the released model,
   and all known collisions or installation contradictions are resolved or
   explicitly prevent design completion;
7. flight and ground software architecture, command/data definitions, safe-state
   behavior, image reconstruction and print workflow are specified sufficiently
   to implement and verify;
8. assembly, inspection and verification procedures define how a future build
   would establish workmanship, functional performance and environmental
   readiness;
9. regulatory, spectrum, debris, launch-integration and independent-review work
   that necessarily depends on a real operator, site, launch or as-built article
   is identified as downstream, with no claim that it has occurred; and
10. an independent reviewer can trace important requirements through decisions,
    parts, calculations, geometry and proposed verification without relying on
    hidden assumptions or unavailable AI reasoning.

## Permitted evidence for this goal

Manufacturer datasheets, manuals, drawings and qualification summaries can
support COTS properties. Published standards, textbooks, papers and government
guidance can support methods and environmental assumptions. Reproducible
calculations, free/open simulations and parametric CAD can support theoretical
viability when their inputs are traceable and their limitations are explicit.

Purchase receipts, incoming inspection and serial-number configuration records
are **not required** for theoretical design completion. Current commercial
obtainability must still be reasonably evidenced because the design is intended
to be buildable, rather than a study of obsolete or fictional hardware.

## Work that remains downstream

The following can remain incomplete after theoretical design release, provided
the design contains a credible verification or reconciliation path:

- purchase, fabrication and as-built configuration control;
- component screening, workmanship inspection and acceptance testing;
- vibration, shock, thermal-vacuum, deployment, EMC and end-to-end RF tests;
- professional structural, electrical, battery-safety and regulatory review;
- FCC/NOAA/NTIA or other applicable filings and approvals;
- exact launch booking, mission-specific ICD reconciliation and integrator
  acceptance; and
- on-orbit operation and mission success.

Those activities determine whether the theoretical design survives contact with
reality. They must never be represented as completed by analysis alone.

## Relationship to the Phase 1 component gate

D1-CMP-STD-001 remains the standard for selecting verifiable components. G1 may
close for the **theoretical design baseline** without purchases or tests when the
exact configurations and every property actually used by the design are supported
or conservatively bounded by authoritative evidence. Unknown properties that are
not used must be labeled and justified as non-controlling. Properties needed only
for later acceptance may remain downstream if the design supplies a verification
method and does not claim the result.

An unavailable private qualification report does not automatically prevent an
education-grade theoretical design. It does prevent claiming the corresponding
qualification. An unavailable command definition, connector pinout, mechanical
drawing or electrical limit that is necessary to connect or operate a selected
part still blocks that selection unless a better-documented part is chosen.

## Completion statement

The permitted final conclusion is: “This is a complete, evidence-traceable,
education-grade theoretical design that appears buildable and viable under its
documented assumptions. It has not been purchased, fabricated, tested,
independently reviewed, licensed, accepted for launch or proven flightworthy.”

The project may not shorten that statement to “flight ready.”

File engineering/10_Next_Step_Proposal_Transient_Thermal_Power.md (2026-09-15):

# D1-AN-THM-001 — Proposed preliminary transient thermal-power model

> **POST-EXECUTION CORRECTION — TMI-001:** The resulting code and numbers are
> retained only as HYPOTHETICAL PARAMETRIC SENSITIVITY — NOT COMPONENT-SPECIFIC.
> Critical thermal properties were assumptions, no physical hardware was tested,
> and the work did not advance THM-002 or EPS-007. See
> `review/incidents/Thermal_Model_Incident.md`.

Revision 0.2 · 2026-09-15 · **APPROVED AND EXECUTED**

## Decision record

The owner approved this bounded analysis task on 2026-09-15. Execution produced
the canonical artifacts listed below and the findings in
`engineering/11_Transient_Thermal_Power_Analysis.md`. Approval covered analysis
and documentation only; no purchase, external contact, fabrication, testing or
flight-release decision was authorized or performed.

## Why this step is next

The present scalar screen calculates equilibrium temperatures but omits thermal
inertia, conductance between parts and the duration of orbital sunlight and
eclipse. It therefore cannot assess battery charge-temperature protection,
heater energy, cold recovery, camera use or radio duty cycling. These are
coupled feasibility questions for the current 1U architecture.

This analysis can make meaningful progress with current public information and
free/open tools. Uncertain orbit, surface, contact and component properties can
be represented as bounded cases and sensitivity variables. Mission-specific
thermal test limits, as-built conductances and model correlation remain
KDD-01/KDD-02/KDD-05/KDD-06 and will not be invented.

## Proposed scope

1. Create a lumped-parameter network with identifiable nodes for the six solar
   panels, structure/rails, battery/EPS, avionics stack, radio/antenna hardware
   and camera bay.
2. Model orbital sunlight/eclipse transitions, solar input, albedo, Earth IR,
   radiation to space, internal mode dissipation and conductive links.
3. Couple battery/heater energy to the existing power model so heat and
   electrical energy use the same operational cases.
4. Run nominal 450, 475 and 500 km cases plus conservative public-information
   bounds for beta angle, optical properties, conductance, internal dissipation,
   initial temperature and degraded power.
5. Include cold startup/recovery, repeated low-generation orbits, hot imaging
   and downlink operations, and heater stuck-on/stuck-off fault cases.
6. Report temperature histories, limit excursions, heater energy, sensitivities
   and which assumptions dominate the result.

## Canonical deliverables

- `analysis/thermal_transient.py` — readable model and solver;
- `analysis/thermal_inputs.json` — values, units, ranges, provenance and evidence
  class for every input;
- `analysis/thermal_cases.csv` and `analysis/thermal_results.csv` — machine-
  readable cases and results;
- plots suitable for technical review;
- `engineering/11_Transient_Thermal_Power_Analysis.md` — equations, sources,
  configuration, results, limitations, numerical checks and design implications;
- updated requirements, open issues, readiness rows, status and configuration
  record if evidence changes.

The implementation will use the bundled Python runtime and free/open Python
libraries already available where practical. The model will retain a
standard-library execution path if a nonessential plotting library is absent.

## Evidence and acceptance criteria

The task is complete when:

- every numerical input has units, provenance and an evidence label;
- energy and sign conventions are documented and conservation residuals are
  checked;
- time-step convergence and at least one analytically checkable limiting case
  are demonstrated;
- results are reproducible from a clean invocation;
- uncertainty/sensitivity results show whether temperature conclusions are
  robust or assumption-driven;
- the model is compared with the current scalar screen and coupled power
  budget;
- no result is labeled `SIMULATED` beyond the configuration and cases actually
  executed; and
- unresolved values are preserved as assumptions, unknowns or known downstream
  dependencies.

This analysis can move THM-002 and EPS-007 forward but cannot close thermal
qualification, flight survival or twelve-month reliability. Those claims still
require released geometry/materials, as-built measurement, physical
thermal-vacuum/balance testing and independent review.

## Cost and boundary forecast

| Cost category | Increment authorized by this proposal |
|---|---:|
| AI expenditure | USD 0 beyond the existing ChatGPT Plus baseline |
| Software/tool expenditure | USD 0 planned |
| Spacecraft hardware expenditure | 0 |
| Ground-station expenditure | 0 |
| Testing/verification expenditure | 0 |
| Regulatory/licensing expenditure | 0 |
| Launch/integration expenditure | 0 |
| External professional/expert-review expenditure | 0 |

Expected boundary: public data are unlikely to establish actual joint
conductance, surface properties, internal EPS losses or flight-unit behavior.
The model should identify how accurately each must later be measured or supplied.
Encountering an input whose uncertainty prevents any useful conclusion will be
recorded as a consumer-AI/public-toolchain boundary rather than concealed.

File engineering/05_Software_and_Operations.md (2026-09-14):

# D1-SW-001 — Flight software and operations specification

Revision A | Software requirements; not executable flight code.

## Runtime architecture

Use the vendor-supported A3200 BSP/RTOS and tested CSP library version. Obtain commercial software license/support terms in the hardware RFQ. Avoid Linux, SD-card root filesystems and unnecessary networking services. Separate time-critical health/recovery tasks from camera capture/compression. Use bounded allocation, queue sizes and CPU time. Camera, radio or I2C timeout cannot block a system-health task.

Boot ROM/internal boot path validates a protected known-good image and a candidate image. Stage updates atomically, verify integrity/authenticity, limit boot attempts and roll back. Confirm that the physical memory map and vendor bootloader support this architecture; it is not assumed from NOR capacity alone. Store configuration in CRC-protected redundant records with monotonic generation counters. Critical RF-disable and mission-end flags survive reset. Memory scrubbing/checksums detect corruption, but no claim of hardware ECC is made.

Allocate watchdog servicing from a health aggregator that requires progress from all critical tasks. Initial timing targets: health sample 10 s, scheduler 1 s, watchdog heartbeat 5 s and external recovery timeout <=60 s; confirm supported EPS/OBC ranges. After three consecutive unsuccessful boots enter the minimal recovery image. EPS supervisor must restore an unresponsive OBC autonomously without depending on the OBC command bus.

## State transitions

| State | Entry / allowed activity | Exit |
|---|---|---|
| INHIBITED | Ground/launch configuration; hazards physically isolated | Valid all-switch separation |
| DELAY | OBC health only; camera and RF off | Valid elapsed release/RF timing |
| DEPLOY | Sufficient battery energy, permitted temperature; bounded release sequence | Telemetry confirms release or retries exhausted |
| COMMISSION | Low duty beacon and command acquisition; no images until authorized and stable | Health and link checkout approved |
| NOMINAL | Duty-budgeted health, image bursts, selective file transfer | Energy/thermal/link fault or end of mission |
| RECOVERY | Camera off; RX 12 s/min; TX <=0.5%; minimal OBC | Sustained energy surplus and thermal conditions |
| RF SILENT | Persistent command or license condition | Authorized explicit release, unless mission end |
| PASSIVATED | Mission end; suppress images/RF; safe energy management | No routine return to service |

Initial SOC thresholds (A): enter recovery below 50%, resume nominal above 70% after two positive-energy orbits, block imaging below 75%, and reserve vendor-safe voltage floor regardless of estimated SOC. Low voltage, temperature or abnormal current can independently force recovery. Validate thresholds with real battery curves and monitor sensor failures. If SOC is invalid, default to the conservative voltage/temperature recovery policy. No setpoint may override battery protection.

## Command and telemetry

Commands: request health; set allowed operating mode; disable RF; request thumbnail/file segment; adjust bounded camera exposure; update approved schedule; reset camera/radio; upload staged firmware; initiate approved passivation. Hazardous commands require authenticated authorization, replay protection and two-step arm/execute with timeout. Design the link/security format around the selected license. Authentication does not imply permission to encrypt traffic in an amateur service.

Each telemetry record contains protocol version, spacecraft ID, sequence, reset counter, timestamp/time validity, mode, battery/solar/rail values, temperatures, deployment status and fault flags. Packets have integrity checks and bounded lengths. Image transfers use image ID, segment index, total segments, per-segment CRC and final file hash; retransmit missing segments only. Retain health packets at highest priority.

AX100 framing is Mode 5 per S11. Confirm supported forward-error options and ground firmware; no legacy AX.25/Viterbi dependency is permitted. Have an independent RF watchdog or EPS-timed radio cutoff to bound unintended TX; verify available hardware behavior. If unavailable, log as a failure-mode gap rather than relying on the main task scheduler.

## Ground segment

Cost baseline: one AX100 ground modem to match flight framing, a suitable carrier/EGSE interface, PC, M2 436CP42UG circular antenna, azimuth/elevation rotator/controller, low-loss coax, bandpass/filtering and surge/weather protection [S28,S29]. The antenna is large (about 5.7 m boom); verify site and mount feasibility. Budget 16 dBi installed antenna gain and <=1 dB receive feed loss, using near-antenna modem placement or an appropriate calibrated front end. Do not assume long unamplified coax meets that loss.

Use 1 W ground RF power only if authorized EIRP, emission and site limits permit. 30 dBm +16 dBi -1 dB feed is a 45 dBm EIRP planning value, not an authorization. Ground model quotes must include two-way operation and the exact Mode 5 waveform. A second ground modem can serve as a development asset; do not count the same radio twice in procurement.

Daily workflow: refresh orbital elements; evaluate pass geometry; check hardware/time synchronization; predict Doppler; receive health before commanding; obey energy flags; request high-priority images; archive raw packets and metadata; reconcile SOC/thermal/reset trends; review conjunction notices. No commanding based solely on unattended image-processing output. Design for remote shutdown and keep an offline command-key backup.

LEOP reserves multiple days for acquisition and catalog identification. Use deployer separation predictions and transmitted unique ID; do not rely on a definitive public orbital element set immediately after launch. Partner ground sites are options subject to agreements and spectrum authority; crowdsourced reception is not guaranteed coverage.

At day 365, confirm mission success evidence then execute authorized end-of-mission operations. Passivation requires supplier-confirmed control of charge sources and stored battery energy; merely turning the OBC off is not passivation. Any residual autonomous recharging or reboot beacon path must be eliminated or explicitly covered in the debris/safety assessment.

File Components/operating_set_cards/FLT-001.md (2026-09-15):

# FLT-001 — 1-Unit CubeSat Structure

**Phase 1 disposition:** CANDIDATE / EVIDENCE INCOMPLETE  
**Segment:** Flight  
**Required function:** Primary 1U structure, rails and enclosure

## Identity and procurement

| Field | Record |
|---|---|
| Manufacturer | ISISPACE |
| Exact identifier/project part | Storefront SKU 100000 |
| Quantity | 1 |
| Order URL | https://www.cubesatshop.com/product/1-unit-cubesat-structure/ |
| Cost and availability | EUR 3,450 indicative storefront; 4-6 weeks stated; exact configuration not quoted |
| Primary source IDs | S06; S01; S33 |

## Engineering properties

| Property | Record |
|---|---|
| Size and mass | About 100 x 100 x 113.5 mm project envelope; 150 g project allocation; manufacturer values UNKNOWN |
| Power or generation | Passive |
| Functional basis | Current 1U order route and provisional EXOpod-compatible allocation |

## Evidence decision

**Gap:** Manufacturer part/configuration, controlled drawing, mass, tolerances, finish, fasteners and qualification evidence incomplete

**Blocked release or analysis:** Structure selection, mass properties, load path and deployer-fit release

This card proposes a required item; it is not procurement authority, an
as-built record, qualification evidence or proof of compatibility.

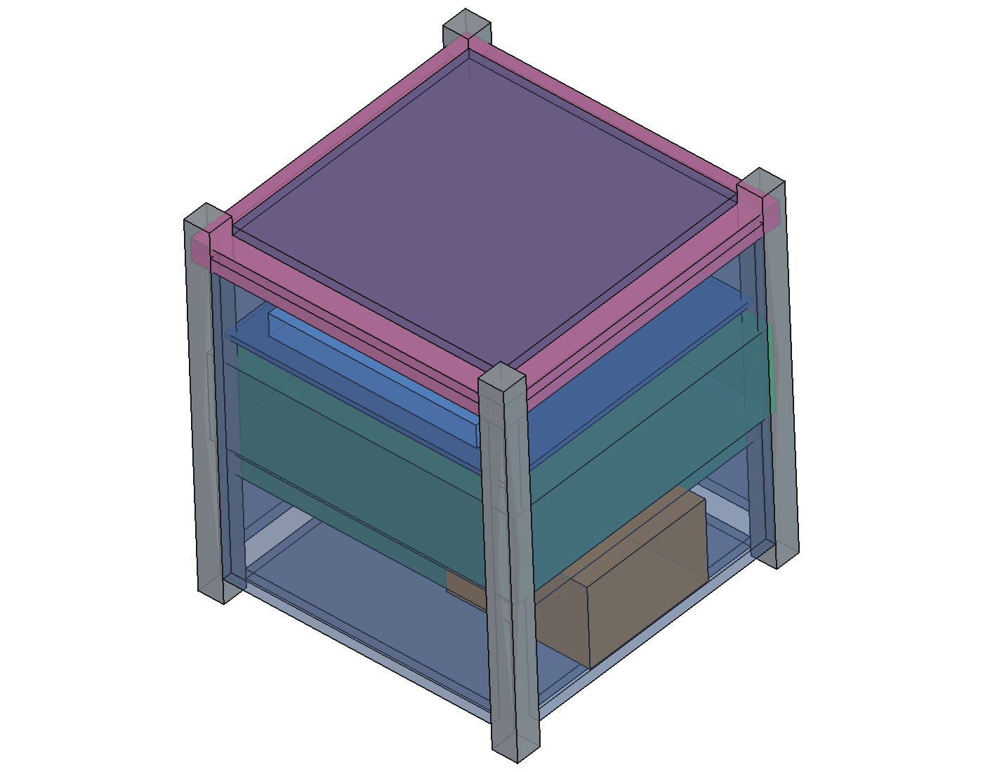
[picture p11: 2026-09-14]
drawings/freecad/exports/assembly.png

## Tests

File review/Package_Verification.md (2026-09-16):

# D1-QA-001 — Issued-package verification

2026-09-14. These are document and analytic-model checks, not hardware tests.

- PASS: Unique BOM IDs
- PASS: Six solar panels including aperture panel
- PASS: BOM mass reconciliation
- PASS: Base hardware cost reconciliation
- PASS: Mass with growth below project target
- PASS: Scalar recovery arithmetic reproduces its stated assumptions; it is not a thermal or hardware requirement pass
- PASS: Fixed-attitude nominal failure explicitly preserved
- PASS: Nominal energy growth reserve accounted
- PASS: Battery stress below permitted 20 percent DOD
- PASS: Downlink >=3dB assumed-threshold reserve
- PASS: Unique source IDs
- PASS: Markdown local links resolve
- PASS: HTML local links and section anchors resolve
- PASS: Recovery and RF screening positive across 450-500 km
- PASS: all source IDs used in narrative documents resolve.
- Drawing SVG rendered to PNG and visually inspected; coordinate-sign formatting corrected before issue.

The executed calculation script passed its internal assertions. BOM and source identifiers, totals and local links were independently checked. This does not close assumptions about thermal, radiation, orbit decay, supplier hardware, regulatory eligibility or physical tests.

2026-09-15 Thermal Model Incident correction: PASS for record consistency. The
model input, generated case rows, verification JSON, report, requirements,
readiness rows, status and mechanical/thermal narrative identify D1-AN-THM-001
as HYPOTHETICAL PARAMETRIC SENSITIVITY — NOT COMPONENT-SPECIFIC. THM-002 is NOT
STARTED and EPS-007 is BLOCKED. Numerical checks validate code behavior only.

2026-09-15 component-audit check: PASS. `Components/generate_component_cards.py`
regenerated 16 cards and one 16-row CSV, with exact B01–B16 ID order and assertions
against the controlled BOM quantities and low/base/high cost allowances. This is a
documentation consistency test, not component verification.

2026-09-15 external-readiness check: PASS. The generator produced 108 unique
matrix IDs, accepted only the six controlled status values, and reconciled the
summary to 3 complete, 21 provisionally addressed, 26 in progress, 28 not
started, 30 blocked and 0 not applicable. This verifies matrix consistency only;
it does not validate the University framework, close any row or constitute an
independent engineering review.

2026-09-15 Phase 1 component-evidence check: PASS for document consistency. The
generator produced 105 property rows for eight recommended COTS candidates and
two audited alternatives. All ten
gate rows are FAIL with disposition CANDIDATE / EVIDENCE INCOMPLETE; the Phase 1
baseline count is zero. The local archive manifest records fourteen manufacturer files,
byte counts, SHA-256 values, exact official URLs, revision/date and retrieval
date. Copyrighted PDFs and page captures are ignored by Git. This check validates record structure,
not component performance, obtainability, compatibility or flightworthiness.

2026-09-15 launch/deployer gate check: PASS. The public trade contains exactly
LD-01 through LD-03 and selects only LD-01 as the provisional mechanical
reference. The regenerated readiness matrix contains 108 unique IDs and
reconciles to 3 complete, 21 provisionally addressed, 27 in progress, 28 not
started, 29 blocked and 0 not applicable. The D1-LCH-001 dimensional screen
reconciles the CAD's nominal 100 x 100 x 113.5 mm envelope and 1.2762 kg growth
mass against the public EXOpod values. No tolerance, physical fit, available
slot, orbit, price, mission ICD or acceptance is claimed.

Orbit sensitivity is in `analysis/orbit_sensitivity.csv`: 400 and 550 km are trade points only. No cheaper available rideshare is asserted without a quote; neither point has a qualified orbital lifetime.

2026-09-15 first-engineering-gate check: PASS for sequencing consistency.
`review/First_Engineering_Gate.md`, the constitution, README, overview, milestone
register, status record, requirements and configuration log all identify Phase 1
component evidence closure as the controlling first engineering gate. M1 and M3
retain their preliminary evidence without further advancement. The gate remains
OPEN with 0 COTS and 0 custom components admitted.

2026-09-15 complete-operating-set check: PASS for list consistency.
`Components/generate_proposed_operating_set.py` produced 29 unique rows and 29
individual component cards: 19 flight and 10 ground. No row is marked `PHASE 1 BASELINE`. Eight custom/site
assemblies have project identifiers and development records; five functions say
`NO COMPLIANT PART IDENTIFIED`. This verifies coverage and labeling only, not
functional compatibility, component compliance or obtainability.

2026-09-16 detailed-baseline ADCS check: PASS for source custody and record
consistency. `D1-ADCS-001` selects the exact K&J `D84` magnet and defines two
custom 95 mm × 1 mm HyMu 80 rods from the published Quetzal-1 flight
architecture. The local archive manifest now contains 23 files; all 23 local
files match their recorded byte counts and SHA-256 hashes. The ADCS remains
`CUSTOM/TO BE VERIFIED`: no Degen-1 magnet moment, rod minor loop, integrated
magnetic survey, cage test or attitude simulation result exists.

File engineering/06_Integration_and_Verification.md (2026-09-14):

# D1-AIV-001 — Assembly, integration and verification plan

Revision A | Planned procedures; no test has been performed on hardware.

## Build sequence and records

1. Freeze mission scope, RF route and candidate orbit. Obtain exact vendor revisions and controlled ICDs. Re-run all model inputs against quotes before ordering flight hardware.
2. Receive and serialize hardware. Capture vendor CoC, acceptance data, firmware versions, battery shipping documentation and storage conditions. Inspect for damage and validate packing lists. Open nonconformances before accepting substitutions.
3. Build an engineering flat-sat with representative EPS/OBC/radio/camera interfaces. Use a battery simulator first, then the protected engineering battery. Validate supply tolerance, inhibit paths, watchdog recovery, radio interoperability and camera file handling before flight-stack assembly.
4. Qualify the D1-IF layout and mechanical details using engineering articles. Test dead shorts, feedback fault behavior, output overshoot and unpowered data pins. Close radiation evidence separately. Do not debug an unverified regulator using flight radio hardware.
5. Assemble the flight structure on an ESD-controlled clean bench with approved tooling. Record fastener torque and locking method from supplier drawings; log material lot/cure records and photographs. Install EPS, adapter, avionics, camera and harnesses in the cleared sequence. Use strain relief and verified connector retention.
6. Check camera focus and boresight, install solar panels, then antenna assembly. Measure power IV curves and complete an RF tune on the final assembly. Verify camera aperture, deployed antenna clearance and all rail envelopes.
7. Run baseline functional, mass/property, dimensional and inhibit tests. Complete environmental testing in approved sequence, followed by repeat functional and optical/RF checks. Any rework after environmental testing receives a documented regression/retest disposition.
8. Load final approved firmware/configuration, archive hashes, verify battery SOC, remove optical cap, install RBF and prepare clean shipping configuration. Perform final integrator fit check and delivery review with traceable closeout evidence.

## Test matrix

| Test ID | Procedure / configuration | Acceptance evidence |
|---|---|---|
| T01 | Dimensional inspection and flight-like dispenser fit | Signed measurement report, interference-free insertion/ejection per ICD, all rail/protrusion limits |
| T02 | Mass, center of mass, inertia measurement | <=actual manifest mass; project target <=1330 g; COM target +/-10 mm; measured inertia |
| T03 | Every power branch across temperature, SOC and load steps | Approved operating voltage at device pins; no absolute maximum exceedance; stable recovery and measured efficiency |
| T04 | All eight inhibit-switch states; source permutations; single failed barriers | No RF/release hazard before allowed state; RBF and debug isolation verified to launch limits |
| T05 | Separation delay, reset/brownout/bounce and stuck-switch injection | No early RF/release; bounded retries; stable inhibited defaults |
| T06 | Solar simulator/shadow sweep, hot/cold IV and one-axis exposure | 2.3 W five faces, 1.8 W aperture face at agreed BOL conditions; cold startup and no reverse-current damage |
| T07 | Orbit power replay: >=72 hours, nominal and fixed-attitude recovery | No declining SOC trend after settling; commanded load/duty and temperatures within budget |
| T08 | Battery capacity and representative life evidence | >=18 Wh usable EOL capacity basis at specified discharge conditions; 6000-cycle mission-profile evidence plus calendar storage |
| T09 | End-to-end radio attenuation/Doppler test, EPS/heater/CPU active | <=1% PER at -123 dBm for selected packet/waveform or reclosed link; +/-11.1 kHz Doppler tracking with residual offsets |
| T10 | Full assembly antenna tuning/pattern measurement | Feed loss, return loss and gain coverage meet approved RF model; stowed and deployed characterization |
| T11 | Image capture, optical focus and smear replay | Recognizable calibrated scene at infinity; exposure, compression and bounded memory/CPU behavior |
| T12 | Random/sine vibration and shock as required, flight-like fixture | Signed tailored profile, monitored response, no damage, post-test function/optics/RF within acceptance limits |
| T13 | Thermal vacuum cycling + thermal balance, functional at plateaus | Correlated thermal model; no charge outside allowed range; no reset/leak/optical failure; heater budget closes |
| T14 | Antenna deployment at cold/hot allowed limits, vacuum where required | Every element deploys and indicates status; bounded release energy; no camera or cell interference |
| T15 | Fault campaign: stuck I2C, radio runaway, corrupt image, brownout, bad boot, lost contact | Recovery reaches defined safe state, no boot loop or uncontrolled TX; health accessible |
| T16 | Radiation evidence review and tests for uncovered parts | Environment/dose/SEE assessment and accepted margin; no unsupported critical-part survivability claim |
| T17 | Rehearsed LEOP, image request, ground loss and mission end | Operations runbooks complete; keys/backup and source passivation verified |
| T18 | Optical/EMI/functional regression after environment | Before/after data comparison within signed limits and all anomalies dispositioned |

## Environment profile tailoring

Before T12/T13 define expected flight environment, qualification/protoflight/acceptance philosophy and allowed hardware pedigree. A cost-minimum approach uses one flight model with supplier design qualification evidence, representative engineering hardware for development and a tailored flight acceptance campaign. Qualification gaps cannot be silently waived to save money. Extra qualification articles belong in the cost risk.

The test readiness package specifies fixture drawings, accelerometer/thermocouple locations, calibration, command script, battery state, inhibit state, frequency/PSD/shock response levels, axis order, durations, notching/abort criteria, chamber pressure and hot/cold dwell criteria. Limits are TBD until the launch provider and analysis agree. Never use component absolute maximum ratings as test setpoints. Thermal cycling and vacuum testing are distinct evidence items; a generic vendor temperature range does not substitute for system thermal balance.

For each test record article serial number, hardware/firmware revision, operator, date, calibrated equipment, setup photos, raw time series, deviations, pass/fail against each requirement and independent reviewer. A claimed pass without raw data and configuration traceability is not a closed requirement.

## Procurement and review gates

PDR: mission scope and candidate architecture; budgets with assumptions; cost trade; no hidden unknowns. CDR/fabrication release: all supplier ICDs closed, full schematics/CAD, structural/thermal/radiation analyses, orbit/regulatory route and flight software architecture accepted. Test readiness: procedures/limits/fixtures approved and hazards controlled. Flight readiness: requirements matrix closed with signed evidence, licensing and manifest approvals in hand, anomalies resolved, configuration frozen. No gate is passed by issuing this document.

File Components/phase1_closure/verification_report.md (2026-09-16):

# Component-register verification

Records checked: 52
Archived source hashes checked: 27
Errors: 0
Warnings: 0

This is an internal consistency and archive-integrity check. It is not engineering validation or independent review.

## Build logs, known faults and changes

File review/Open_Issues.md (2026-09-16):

# D1-RVW-001 — Open issues and release gates

Revision A. The package is ready for an aerospace engineer to audit its choices, assumptions and missing evidence. It is not a completed CDR or a manufacturing release. Critical and high items below block a claim of demonstrated launch survival and twelve-month capability.

| ID | Priority | Issue | Owner role | Closure artifact | Requirements |
|---|---|---|---|---|---|
| O01 | Critical | EXOpod Nova is only a provisional mechanical reference; launch mission, integrator contract, target orbit and mission ICD are not selected | Systems/mission | Written offer/contract and signed ICD; injection/collision/decay/demise analysis | R01,R03,R21,R25 |
| O02 | Critical | RF authorization and band unresolved; 437MHz conditional | Regulatory/RF | Approved service/frequency and ground authority; update hardware if needed | R17 |
| O03 | Critical | Thermal feasibility is unknown. D1-AN-THM-001 used unsupported thermal properties and is retained only as hypothetical sensitivity under TMI-001 | Thermal/EPS | Selected component property evidence, released thermal interfaces, component-specific model, correlation and verified controls | R08,R10,R22; review/incidents/Thermal_Model_Incident.md |
| O04 | Critical | EPS 3.3V tolerance incompatible with direct avionics connection | Electrical | Released adapter/protection or guaranteed supplier interface; environmental/radiation verification | R15,R23 |
| O05 | Critical | Three-inhibit independence and solar paths unproven | Safety/EPS | Supplier circuit review/fault tree and all-state test | R11,R13 |
| O06 | Critical | Radiation critical-part evidence missing | EEE | Orbit/dose/SEE assessment; lot/revision evidence or qualification | R01,R23 |
| O07 | High | Camera-aperture panel and 1U stack fit not established | Mechanical/payload | Vendor CAD, aperture cell layout and power guarantee; build fit | R03,R27 |
| O08 | High | DMC-3 has a current quote route, but the exact option configuration, delivered revision, price and supply commitment are unresolved | Procurement | Complete OSF 1012964 from a released pin map; later reconcile quote/delivered revision before purchase | R06,R15 |
| O09 | High | Camera electrical/power/shutter/Sun exposure/JPEG details gated | Payload | Current CS-101 brief and confirmed configuration plus tests | R02,R28,R29 |
| O10 | High | NOAA license/determination not obtained | Regulatory | Full-capability filing and required authority | R18 |
| O11 | High | One-year battery evidence and passivation behavior unknown | EPS | 6000-cycle/calendar evidence and source passivation verification | R09,R26 |
| O12 | High | Mode5 sensitivity/pattern/contacts not demonstrated | RF/ops | Actual threshold, radiation pattern and pass simulation | R16,R19 |
| O13 | High | No structural FEA/environment profiles/test reports | Mechanical/AIV | Accepted loads model, margins and final assembly tests | R21,R30 |
| O14 | High | No quantified image opportunity rate with the selected passive magnetic attitude architecture; roll about the magnet axis remains weakly controlled | Mission/payload/GNC | Attitude/orbit Monte Carlo using measured D84/rod/residual-dipole data and final inertia, followed by scene replay; accept opportunity risk | R02 |
| O15 | Medium | All selected flight prices are estimates | Procurement | Comparable quotes with tests/software/support separated | R06,R32 |
| O16 | High | Flight firmware and boot recovery only specified | Software | Implemented versioned code and fault-injection/rehearsal evidence | R14,R20 |

## Review disposition

PDR: candidate design, conditional budget closure. CDR: NOT PASSED. Fabrication release: NOT PASSED. Test readiness: NOT PASSED. Flight readiness: NOT PASSED.

Systems reviewer: __________ Date: __________
Electrical/safety reviewer: __________ Date: __________
Mechanical/thermal reviewer: __________ Date: __________
Radiation/reliability reviewer: __________ Date: __________
RF/regulatory reviewer: __________ Date: __________
Payload/operations reviewer: __________ Date: __________

The owner approved opportunistic Earth imagery, US operation and nominal 450–500 km with flexibility for a lower-cost rideshare. No arbitrary financial ceiling applies. In-scope engineering decisions may be refined without changing those requirements. Targeted imagery or guaranteed spatial resolution requires a new mission baseline.
| O17 | High | Thermal Model Incident: executable calculation was mistaken for component evidence because critical inputs were assumptions; full component-specific thermal, orbit-decay and radiation analysis remain unexercised | Experiment/toolchain | Enforce source-completeness gates; record each boundary and never replace missing critical properties with generic values | Constitution §§21–24; TMI-001 |
| O18 | Medium | Actual AI subscription/tooling spend has not been reconciled against account records | Experiment/accounting | Update Project_Cost_Ledger.csv and Project_Status.yaml with verified amounts and dates | Constitution §22 |

## CAD-001 accommodation findings

| ID | Priority | Issue / assumptions | Owner role | Closure artifact | Requirements |
|---|---|---|---|---|---|
| O19 | High | Rail/board/EPS/AntS bounding envelopes intersect; CAD-A01/A02 and CAD-C01 | Mechanical | Controlled frame and selected component corner profiles, mounting and tolerance stack | R03,R21,R30 |
| O20 | High | Provisional solar panel geometry intersects EPS/AntS/camera; CAD-A04 and CAD-C02–C05 | Mechanical/payload/EPS | Agreed panel footprint, stackup, aperture, cell string routing and camera bracket | R03,R07,R27 |
| O21 | High | DMC carrier and module placements, mating heights, connectors, harness and deployment sweep unknown; CAD-A03/CAD-C06/C07 | Mechanical/RF | Released carrier ICD, connector access/bend radii, antenna sweep and lens pupil/FOV checks | R03,R12,R16,R28,R30 |
| O22 | High | Assigned BOM mass is not CAD material mass; 295 g unmodeled/unlocated; COM not credible | Mechanical | As-ordered masses/COM, frame and mounting geometry, complete mass reconciliation | R04,R05 |

Dimension provenance, provisional values and documented-design -> CAD-conflict ->
proposed-correction records are in [CAD traceability](../drawings/freecad/TRACEABILITY.md)
and [CAD findings](../drawings/freecad/FINDINGS.md). No correction changes the architecture yet.

## External readiness audit findings — 2026-09-15

| ID | Priority | Issue | Owner role | Closure artifact | Readiness rows |
|---|---|---|---|---|---|
| O23 | Critical | No independent aerospace feasibility review has occurred; current evidence is AI-generated and self-audited | Chief engineer/independent review board | Reviewer qualifications, signed review record, findings and dispositions | GOV-007,GOV-010,MIS-008 |
| O24 | High | No named project organization, decision authority, WBS, resource-loaded schedule or committed funding plan | Owner/project manager | Accepted RACI/authority matrix, WBS, critical-path schedule and funding gate | GOV-003–005 |
| O25 | High | Requirements and T01–T18 are preliminary but not a closed bidirectional verification baseline with executable procedures | Systems/AIV | Approved requirements baseline, verification cross-reference and detailed procedures | SYS-003,SYS-004,AIV-003 |
| O26 | High | Ground site, station design, software, contact analysis and trained operators are absent | Ground/RF/operations | Site survey, released ground BOM/design, software, coverage analysis and rehearsal records | GRD-001–006,OPS-003 |
| O27 | Critical | Legal operator/entity and accountable regulatory contacts are undefined, blocking defensible FCC/NOAA/FAA paths | Owner/regulatory | Operator identity/ownership record, licensing strategy and responsible contacts | REG-001–007 |
| O28 | High | No complete materials/processes/outgassing list, detailed hazard reports or battery transport package exists | Materials/safety/QA | As-built materials/process list, hazard analyses and accepted battery/shipping evidence | MEC-008,MEC-009,LCH-003,REG-009 |
| O29 | High | Verification article strategy, facilities, fixtures, EGSE, calibration and quality system are not baselined | AIV/QA/project manager | Approved model philosophy, facility/equipment plan, quality/AIT plan and funded schedule | AIV-001–005 |

The complete 108-item audit and closure criteria are in
[Master CubeSat Readiness Checklist](Master_CubeSat_Readiness_Checklist.md).
These findings lower the honest project maturity assessment to Constitution
Level 0 with partial progress toward Level 1; they do not alter the spacecraft
architecture.

## Launch and deployer constraint-gate findings — 2026-09-15

| ID | Priority | Issue | Owner role | Closure artifact | Requirements |
|---|---|---|---|---|---|
| O30 | Critical | Public EXOpod Nova documentation does not supply a 1U price, available mission/orbit, customer electrical safety and battery rules, test levels, delivery schedule or signed acceptance criteria | Owner/systems/launch integration | Common mission data sheet; comparable written EXOLAUNCH/ISISPACE responses; selected offer and controlled mission ICD | R01,R03,R06,R11–R13,R21,R25 |
| O31 | High | CAD matches nominal Nova envelope numbers but lacks rail tolerances/profile/finish, switch and RBF access, credible COG/inertia and physical fit evidence | Mechanical/AIV | Controlled B01 CAD/certificates, tolerance analysis, complete mass properties and Nova/TestPod fit/ejection report | R03–R05,R21,R30 |

The three-path trade and conflict records LDC-01–LDC-06 are in
[D1-LCH-001](../engineering/09_Launch_and_Deployer_Baseline.md). The reference
selection changes planning evidence only. It does not close O01, O05, O13,
LCH-001, LCH-002 or AIV-006.

## Phase 1 component-evidence findings — 2026-09-15

| ID | Priority | Issue | Owner role | Closure artifact | Requirements |
|---|---|---|---|---|---|
| O32 | Critical | No physical component currently passes the complete Phase 1 mission-relevant public-evidence gate; several BOM lines are allowances rather than identified parts | Systems/procurement/subsystem leads | Property matrix with no required UNKNOWN/CONFLICT rows for each admitted part; exact configurations and archived/hash-controlled primary sources | R01,R03,R06–R10,R14–R23 |
| O33 | Critical | ICEPS2 current page and linked issue 1.2 datasheet disagree on Type A battery energy/configuration | EPS/safety | Reconciled exact Type A configuration and controlled evidence; revised energy/life analysis | R08–R10,R22 |
| O34 | High | CS-101 lacks public mission-critical data; piCAM/FM is better documented but still lacks enough evidence for baseline admission | Payload/radiation/EPS | Selected exact camera with complete property evidence, interface design and verification plan | R14–R18,R23 |
| O35 | High | DMC-3 availability was previously recorded incorrectly; current documents exist, but its order-option configuration is not selected | CDH/integration | Completed OSF 1012964 configuration and pin-by-pin interface review | R06,R07,R19,R21 |

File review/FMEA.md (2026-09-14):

# D1-RAM-001 — Preliminary functional FMEA

Qualitative screening; no unsupported failure rates or numeric mission reliability are assigned. Systematic/common-cause faults and critical single-string elements remain. This is the starting point for the detailed hardware FMECA and launch hazard fault trees.

| ID | Failure | Effect | Mitigation | Residual / verification |
|---|---|---|---|---|
| F01 | Battery internal failure | Loss of mission; launch hazard | Pack protection/retention; supplier safety pedigree | Single pack remains a single point; T08/T12 |
| F02 | EPS or regulator destructive SEE | Loss of command/power | Part evidence, limiting, independent reset paths | Watchdog cannot repair damage; T16 |
| F03 | Adapter overvoltage/feedback fault | Avionics damage | Protected/guaranteed supply interface required | Unclosed topology blocks release; T03 |
| F04 | OBC hang or memory corruption | Lost commanding/unsafe schedule | External watchdog, recovery boot, CRC and bounded tasks | Same CPU remains critical; T15 |
| F05 | Camera hang/short/full buffer | Potential bus/power starvation | Separate switched supply, timeouts and storage partition | Image loss acceptable temporarily; T11/T15 |
| F06 | Insufficient solar due to fixed attitude | Battery depletion | Six faces, reduced recovery load, SOC trends | Aperture face minimum and heater assumptions critical; T06/T07 |
| F07 | One panel open or short | Loss of geometric energy guarantee | Axis blocking, branch protection, reduced duty | Year mission not guaranteed after face loss; T06 |
| F08 | Heater stuck on/off or sensor wrong | Battery freeze/overheat/depletion | Independent thermal cutoff, validity checks and timeout | Actual EPS implementation open; T13/T15 |
| F09 | Antenna fails to release | No usable link or severe loss | Redundant release elements, bounded retries, thermal test | Common restraint/system remains critical; T14 |
| F10 | Inadvertent RF/release in dispenser | Launch/other spacecraft hazard | Independent physical inhibits, source-path analysis | Three switch count alone inadequate; T04/T05 |
| F11 | RF stuck transmitting | Energy loss/interference | Independent TX duration limit/power cutoff | Implementation must be shown; T09/T15 |
| F12 | Ground loss or key loss | No image return/commands | Recovery schedule, backups, alternate authorized station | No assured external station agreement; T17 |
| F13 | Fast spin or camera facing space | Unrecognizable images | Exposure selection, burst diversity, thumbnails | No active pointing; Monte Carlo closure O14 |
| F14 | Lens focus shift or contamination | Image mission loss | Qualified retention, cap closeout, optical tests | Camera qualification evidence required; T11/T18 |
| F15 | Excessive orbit lifetime/early decay | Disposal violation or <12 month life | Orbit selection under density uncertainties | No propulsion remedy in current BOM; O01 |
| F16 | Connector/joint loosening | Intermittent or permanent failure | Qualified locking, strain relief, flight assembly acceptance | Actual torque and preload drawing needed; T12 |
| F17 | Unauthorized command | RF/power/payload misuse | Authentication, replay prevention, bounded parameters | License-compatible security configuration; T15 |
| F18 | Post-mission charge/reboot persists | Stored energy and RF persist | Verified charge/source passivation and persistent flags | Supplier capability open; T17 |

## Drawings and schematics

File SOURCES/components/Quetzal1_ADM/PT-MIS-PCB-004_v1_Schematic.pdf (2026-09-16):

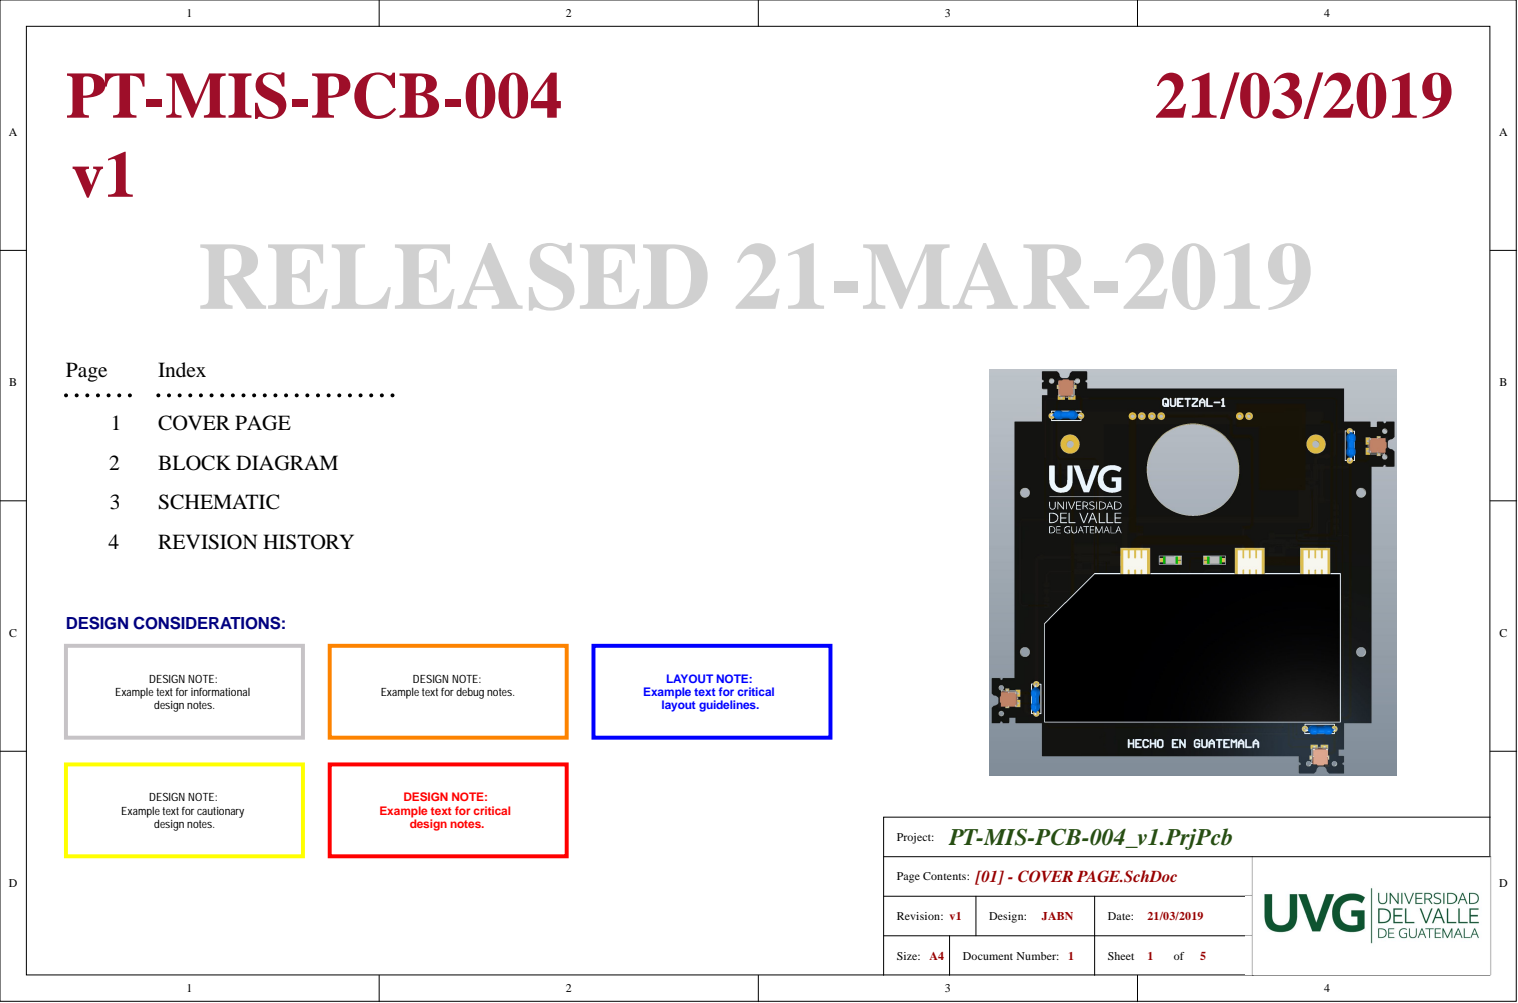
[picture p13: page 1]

DESIGN NOTE:
Example text for debug notes.

LAYOUT NOTE:
Example text for critical
layout guidelines.

Example text for informational

Example text for cautionary
design notes.

PT-MIS-PCB-004_v1.PrjPcb

Page Contents: [01] - COVER PAGE.SchDoc

Revision: v1 | Design: JABN | Date: 21/03/2019

Size: A4 | Document Number: 1 | Sheet 1 5 of

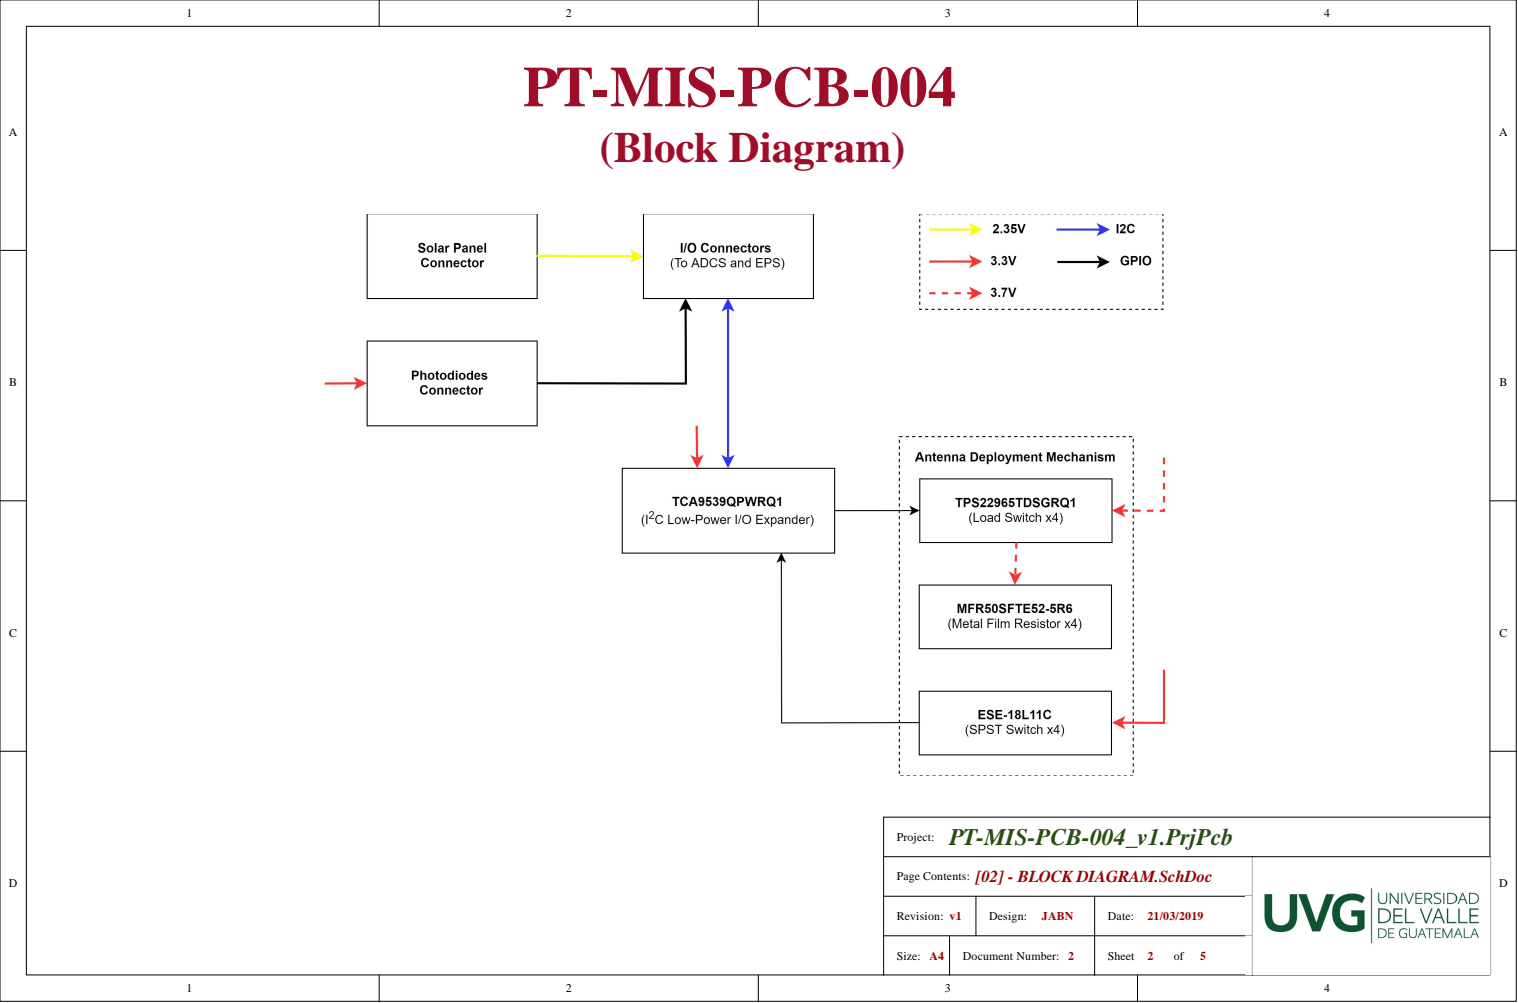
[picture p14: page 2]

PT-MIS-PCB-004_v1.PrjPcb

Page Contents: [02] - BLOCK DIAGRAM.SchDoc

Revision: v1 | Design: JABN | Date: 21/03/2019

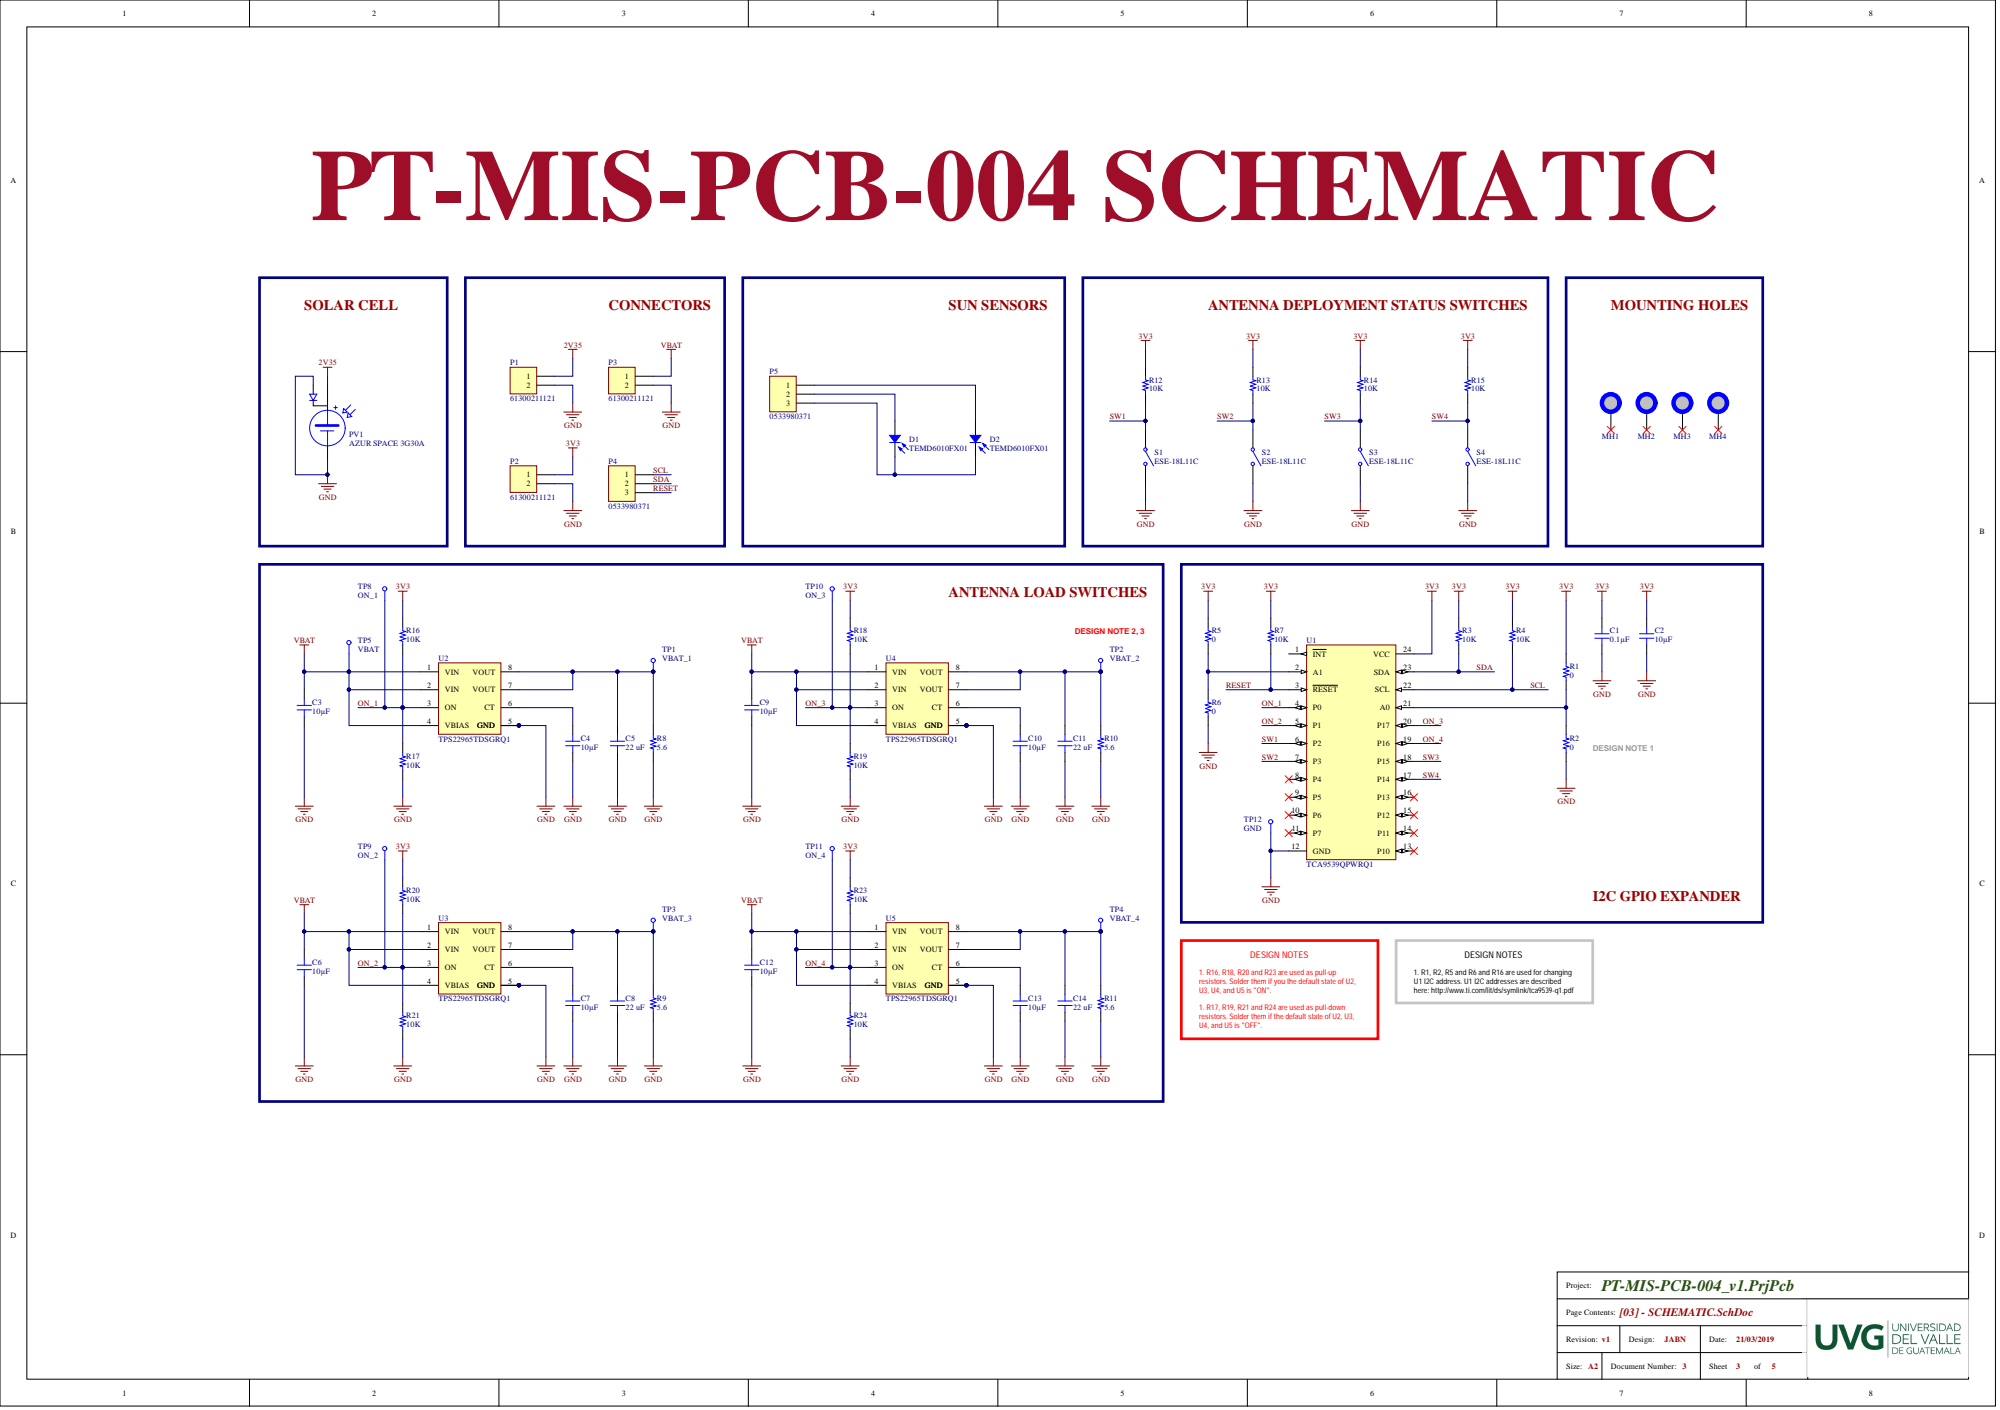
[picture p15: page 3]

PT-MIS-PCB-004 SCHEMATIC

1. R16, R18, R20 and R23 are used as pull-up resistors. Solder them if you the default state of U2, U3, U4, and U5 is "ON". DESIGN NOTES

1. R1, R2, R5 and R6 and R16 are used for changing U1 I2C address. U1 I2C addresses are described

here: http://www.ti.com/lit/ds/symlink/tca9539-q1.pdf

1. R17, R19, R21 and R24 are used as pull-down resistors. Solder them if the default state of U2, U3, U4, and U5 is "OFF".

Page Co n ten t s

Rev i s i o n : | | Date:

Size: A 2 Sheet | D ocumen t N umber: | 3 o f 5

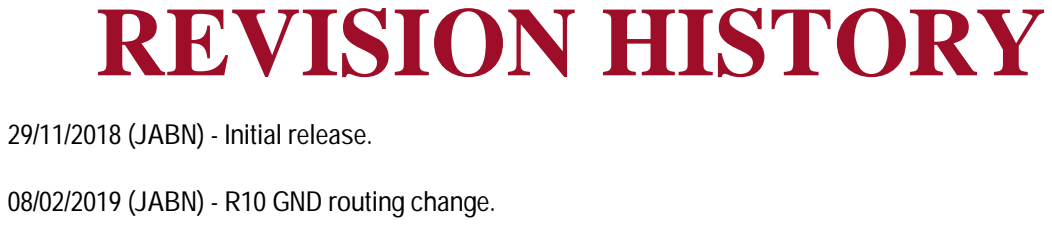
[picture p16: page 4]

08/02/2019 (JABN) - R10 GND routing change.

PT-MIS-PCB-004_v1.PrjPcb

Page Contents: [04] - REVISION HISTORY.SchDoc

Revision: v1 | Design: JABN | Date: 21/03/2019

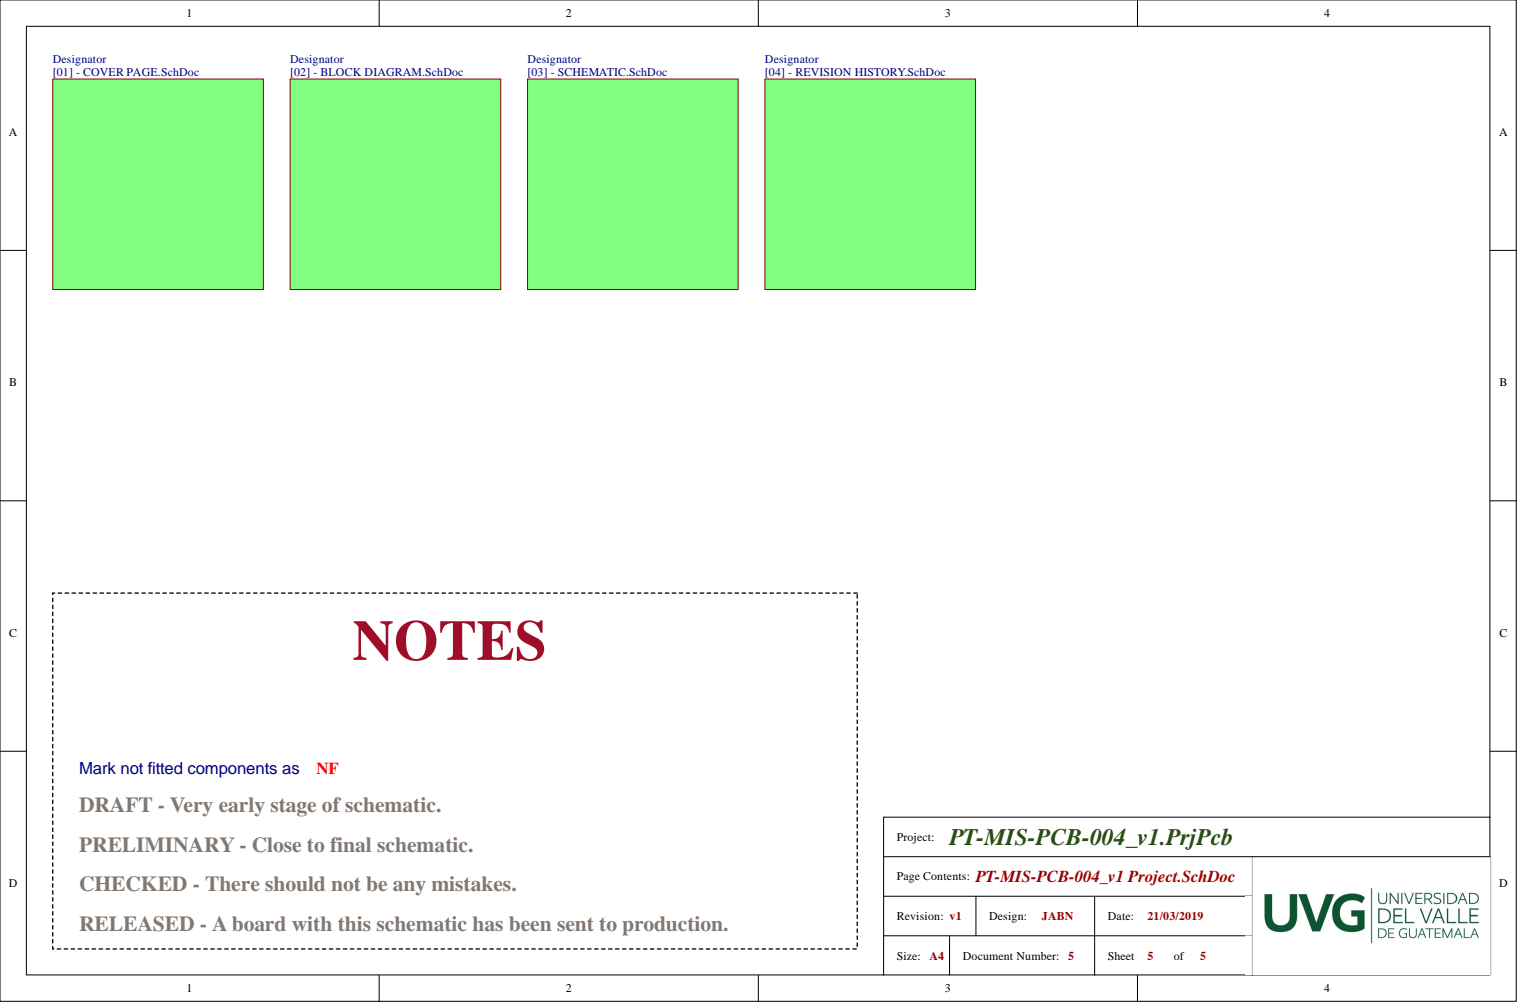
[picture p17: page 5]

Mark not fitted components as NF
DRAFT - Very early stage of schematic.

PT-MIS-PCB-004_v1.PrjPcb

PRELIMINARY - Close to final schematic.

Page Contents: PT-MIS-PCB-004_v1 Project.SchDoc

CHECKED - There should not be any mistakes.

RELEASED - A board with this schematic has been sent to production.

Revision: v1 | Design: JABN | Date: 21/03/2019

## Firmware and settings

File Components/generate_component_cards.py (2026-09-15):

#!/usr/bin/env python3
"""Generate DEGENERATE-1 component audit cards and the summary CSV.

The data below contains exactly the 16 lines already present in procurement/BOM.csv.
Do not add a record here without first changing the controlled project BOM.
"""

from __future__ import annotations

import csv
from pathlib import Path


ROOT = Path(__file__).resolve().parent
AUDIT_DATE = "2026-09-15"

COMMON_ISIS_SOLAR = {
    "vendor_facts": [
        "1U panel catalog mass: 50 g, configuration dependent.",
        "Typical panel thickness: 1.2–2.0 mm; planform and mounting-hole drawing are not published on the current page.",
        "Approximate BOL output: 1.23 W and 2.7 V per GaAs cell; 30% BOL cell efficiency.",
        "Custom flat inline Omnetics interface, 2 mm height; included Raychem Spec 44 AWG26 harness.",
        "Integrated temperature sensor and photodiode.",
        "Operating range: -40 °C to +80 °C; catalog radiation statement: minimum two years in LEO.",
        "Shipped-unit acceptance includes functional test and thermal cycling; current page does not show acceptance TVAC, vibration, or shock.",
    ],
    "order_url": "https://www.isispace.nl/product/small-satellite-solar-panels/",
    "order_route": "Select 1U and use the vendor's ‘I want to buy’ quote route. This is a configured item, not a stock checkout.",
    "price_evidence": "No public price. Project planning allowance only.",
    "availability": "Catalog family is current; exact face configuration, lead time, and deliverable revision require written quotation.",
    "sources": ["S04", "S22", "procurement/BOM.csv", "engineering/01_Mission_and_Architecture.md", "engineering/02_Budgets_and_Analyses.md", "engineering/03_Interfaces.md"],
}


COMPONENTS = [
    {
        "id": "B01", "slug": "ISISPACE_1U_structure", "vendor": "ISISPACE", "item": "1U structure, rails, fasteners, separation provisions", "qty": 1,
        "kind": "COTS structure with project-specific configuration", "mass": "150 g", "mass_basis": "PROJECT ALLOCATION; current storefront does not publish mass",
        "size": "Nominal spacecraft rail envelope about 100 × 100 × 113.5 mm", "size_basis": "PROJECT ALLOCATION from CubeSat form factor; controlled structure and deployer drawings remain required",
        "power": "No electrical load", "power_basis": "Physical structure",
        "cost": (2000, 3000, 4500), "published_price": "€3,450 shown by CubeSatShop on 2026-09-15; taxes, freight, options, and configuration scope unknown",
        "order_url": "https://www.cubesatshop.com/product/1-unit-cubesat-structure/", "order_route": "Request more information through CubeSatShop/ISISPACE; storefront SKU 100000.",
        "availability": "Storefront states 4–6 weeks, but this is not a supplier quotation or confirmation for the required flight configuration.",
        "vendor_facts": ["Generic modular 1U structure with load-carrying frames and detachable shear panels.", "Current storefront says flight heritage since 2012.", "One internal 1U PCB/module stack is described."],
        "configuration": ["Provide rails, frames, shear panels, secondary structure, approved board-mount hardware and fasteners.", "Accommodate the project-required three independent separation-switch/RBF architecture without rail or panel interference.", "Use the exact launch-provider/deployer ICD selected later."],
        "interfaces": ["Dispenser rails and envelope", "Internal board stack and standoffs", "Six body-mounted panel interfaces", "Separation switches/RBF"],
        "open": ["Exact order code and delivered kit content", "Controlled dimensions, tolerances, materials, coatings, fastener specifications, torque, venting and CAD", "Switch locations, travel and compatibility with B04", "As-ordered mass and center-of-mass contribution", "Whether the 4–6 week statement applies to this configuration"],
        "sources": ["S01", "S06", "procurement/BOM.csv", "engineering/02_Budgets_and_Analyses.md", "engineering/04_Mechanical_Thermal_Radiation.md", "drawings/freecad/FINDINGS.md"],
    },
    {
        "id": "B02", "slug": "ISISPACE_ICEPS2_Type_A", "vendor": "ISISPACE", "item": "ICEPS2 Type A with integrated battery and three-separation-switch/RBF option", "qty": 1,
        "kind": "COTS EPS/battery requiring configured safety option", "mass": "184 ± 5 g", "mass_basis": "CURRENT VENDOR PAGE; includes battery",
        "size": "96 × 92 × 26.45 mm, PCB and top battery", "size_basis": "CURRENT VENDOR PAGE; project CAD uses 26.5 mm from S03",
        "power": "Stores 22.5 Wh per current product page; VD0 unregulated, four VD1 5 V channels, four VD2 3.3 V channels; project peak delivered-load screen is 6.444 W and 1.26 A battery-side at 6 V", "power_basis": "VENDOR catalog plus PROJECT CALCULATION; per-channel transient closure is open",
        "cost": (4500, 6500, 9000), "published_price": "No public price; project planning allowance only",
        "order_url": "https://www.isispace.nl/product/compact-electrical-power-system/", "order_route": "Select Type A and use ‘I want to buy’/sales contact for a configured quotation.",
        "availability": "Current product family; exact switch/RBF option, electrical revision, lead time, battery lot, and acceptance scope require quote.",
        "vendor_facts": ["Type A has an integrated two-cell Li-ion pack.", "I²C control; hardware MPPT; emergency low-power behavior, supervisor/watchdog, housekeeping, overcurrent/thermal and reverse-current protection are listed.", "Operating range is -20 °C to +70 °C at product level.", "Shipped-unit acceptance shown: functional and thermal cycling; not TVAC, vibration, or shock."],
        "configuration": ["Type A only; do not add a separate battery BOM line.", "Request three-separation-switch/RBF implementation and evidence of source-to-hazard inhibit independence.", "Accept five unequal/intact two-cell faces plus one camera-aperture face across three MPPT inputs as defined by H01–H03.", "Use switched 5 V outputs for the two D1-IF branches and 5 V AntS branch."],
        "interfaces": ["H01–H03 solar/MPPT", "H04/H05 switched 5 V to D1-IF", "H06 switched 5 V to AntS", "H08 I²C", "H11 switches/RBF", "H12 service"],
        "open": ["Current product page says 22.5 Wh while the linked S03 revision shows a different Type-A energy/configuration value; obtain an as-ordered controlled datasheet", "Exact output current limits, startup/transients and 3.3 V high-side tolerance for delivered revision", "Battery charge/discharge temperature/current profile and ≥6000 shallow-cycle plus calendar-life evidence", "Complete inhibit topology including solar, battery, debug and backfeed paths", "Delivered-lot qualification/acceptance and radiation/SEE evidence"],
        "sources": ["S02", "S03", "procurement/BOM.csv", "engineering/02_Budgets_and_Analyses.md", "engineering/03_Interfaces.md", "engineering/04_Mechanical_Thermal_Radiation.md"],
    },
    {
        **COMMON_ISIS_SOLAR, "id": "B03", "slug": "ISISPACE_1U_side_solar_panels", "vendor": "ISISPACE", "item": "1U side solar panel, two cells in series", "qty": 3,
        "kind": "COTS-derived custom solar-panel configuration", "mass": "50 g each; 150 g line total", "mass_basis": "CURRENT VENDOR PAGE, configuration dependent",
        "size": "Planform unknown; 1.2–2.0 mm typical thickness", "size_basis": "CURRENT VENDOR PAGE for thickness; project CAD planform is an ASSUMPTION",
        "power": "Procurement target ≥2.3 W BOL per panel; two series cells approximately 5.4 V BOL using current catalog values", "power_basis": "PROJECT REQUIREMENT plus CURRENT VENDOR approximate per-cell values",
        "cost": (1200, 1800, 2500), "published_price": "No public price; project planning allowance per panel",
        "configuration": ["Three 1U body-mounted side panels for the documented side faces.", "Two cells in series per face; opposite faces parallel only through approved blocking paths into the assigned MPPT.", "Guaranteed ≥2.3 W BOL under supplier-stated conditions; no deployable panels."],
        "interfaces": ["H01–H03 to ICEPS2 MPPT", "Custom flat inline Omnetics and included AWG26 harness", "ISISPACE structure mounting"],
        "open": ["Exact face assignment for each ordered serial number", "Planform, hole pattern, cell layout, connector placement and cable length", "Hot/cold IV curves and startup/MPPT compatibility", "Reverse-current/blocking topology", "As-ordered mass, acceptance tests, lead time and price"],
    },
    {
        **COMMON_ISIS_SOLAR, "id": "B04", "slug": "ISISPACE_1U_minusZ_solar_panel", "vendor": "ISISPACE", "item": "1U -Z solar panel with separation-switch clearances", "qty": 1,
        "kind": "COTS-derived custom solar-panel configuration", "mass": "50 g", "mass_basis": "CURRENT VENDOR PAGE, configuration dependent",
        "size": "Planform and relief geometry unknown; 1.2–2.0 mm typical thickness", "size_basis": "CURRENT VENDOR PAGE for thickness",
        "power": "Procurement target ≥2.3 W BOL; two series cells approximately 5.4 V BOL", "power_basis": "PROJECT REQUIREMENT plus CURRENT VENDOR approximate per-cell values",
        "cost": (1200, 1800, 2500), "published_price": "No public price; project planning allowance",
        "configuration": ["Body-mounted -Z panel with supplier-designed clearances for the actual separation-switch/RBF hardware.", "Two cells in series and ≥2.3 W BOL under specified conditions.", "No cell cutting or ad-hoc field modification."],
        "interfaces": ["H01–H03 to ICEPS2 MPPT", "Structure, rail and switch keep-outs", "Custom flat inline Omnetics and included AWG26 harness"],
        "open": ["Actual switch count, locations and travel", "Signed panel relief, cell routing and structural drawing", "Hot/cold IV curves, blocking path and MPPT compatibility", "As-ordered dimensions, mass, price, lead time and acceptance evidence"],
    },
    {
        **COMMON_ISIS_SOLAR, "id": "B05", "slug": "ISISPACE_1U_plusZ_AntS_solar_panel", "vendor": "ISISPACE", "item": "1U +Z solar panel for AntS mounting", "qty": 1,
        "kind": "COTS-derived custom solar-panel configuration", "mass": "50 g", "mass_basis": "CURRENT VENDOR PAGE, configuration dependent; no AntS cover mass credit taken",
        "size": "Planform/interface unknown; 1.2–2.0 mm typical thickness", "size_basis": "CURRENT VENDOR PAGE for thickness",
        "power": "Procurement target ≥2.3 W BOL; two series cells approximately 5.4 V BOL", "power_basis": "PROJECT REQUIREMENT plus CURRENT VENDOR approximate per-cell values",
        "cost": (1200, 1800, 2500), "published_price": "No public price; project planning allowance",
        "configuration": ["Top panel mounted using the AntS-supported accommodation.", "UHF turnstile deployment must remain unobstructed.", "Two cells in series and ≥2.3 W BOL under specified conditions."],
        "interfaces": ["AntS top mounting interface", "H01–H03 to ICEPS2 MPPT", "Custom flat inline Omnetics and included AWG26 harness"],
        "open": ["Signed AntS/panel mechanical interface and whether supplied cover is retained or replaced", "Antenna-element stow/deployment clearances", "Cell/connector routing and RF interaction", "Hot/cold IV, MPPT compatibility, mass, price and acceptance evidence"],
    },
    {
        "id": "B06", "slug": "GomSpace_NanoMind_A3200", "vendor": "GomSpace", "item": "NanoMind A3200 flight computer", "qty": 1,
        "kind": "COTS flight computer", "mass": "24 g including shield", "mass_basis": "S08 VENDOR DATASHEET",
        "size": "65 × 40 × 7.1 mm", "size_basis": "S08 VENDOR DATASHEET",
        "power": "3.2–3.4 V supply; vendor table gives 23–45 mA for listed clock/workload states, with additional sensor/flash loads; project allocates 0.18 W nominal, 0.08 W recovery and 0.9 W peak", "power_basis": "S08 VENDOR DATASHEET plus PROJECT ALLOCATIONS; peak is not a measured mission value",
        "cost": (3500, 5500, 8000), "published_price": "No public price; project planning allowance only",
        "order_url": "https://gomspace.com/product/nanomind-a3200/", "order_route": "Use GomSpace quote request/contact; obtain exact sales code, hardware revision and software entitlement.",
        "availability": "Current product page; stock, lead time, current revision, BSP and support terms are unconfirmed.",
        "vendor_facts": ["AVR32 MCU; 512 KB internal flash, 128 MB NOR flash, 32 kB FRAM and 32 MB SDRAM.", "I²C, UART, CAN, external SPI, ADC/GPIO, GSSB and PWM interfaces.", "Integrated magnetometer, gyroscope, RTC and temperature sensors.", "Operating temperature -30 °C to +85 °C; datasheet says environment tests were performed but directs users to GomSpace for details."],
        "configuration": ["Top-side module on B08 DMC-3.", "Powered from D1-IF branch A at 3.30 V nominal; no direct ICEPS2 3.3 V connection.", "CAN/CSP to B07; separate I²C branches to EPS and AntS; camera serial interface subject to supplier option."],
        "interfaces": ["Two 20-position hard-gold FSI connectors", "H04 power", "H07 CAN/CSP", "H08/H09 I²C", "H13 camera serial"],
        "open": ["Exact order code/current hardware revision and whether A3200 remains recommended for new designs", "BSP, bootloader, libraries, licenses, source access and support cost", "DMC-3 mechanical/electrical compatibility and connector stack height", "Mission-workload current and sleep/wake timing", "Radiation/SEE and delivered-unit acceptance evidence"],
        "sources": ["S07", "S08", "procurement/BOM.csv", "engineering/02_Budgets_and_Analyses.md", "engineering/03_Interfaces.md"],
    },
    {
        "id": "B07", "slug": "GomSpace_NanoCom_AX100U", "vendor": "GomSpace", "item": "NanoCom AX100-U, sales part 200315, Mode 5", "qty": 1,
        "kind": "COTS UHF transceiver", "mass": "24.5 g", "mass_basis": "CURRENT VENDOR PAGE and S10",
        "size": "65 × 40 × 6.5 mm", "size_basis": "CURRENT VENDOR PAGE and S10",
        "power": "3.3 V supply; RX 45/55/120 mA min/typ/max; TX 750/800/850 mA at +25 °C and up to 1 A across -30 to +85 °C; project allocates 0.20 W RX and 3.3 W TX", "power_basis": "S10 VENDOR DATASHEET plus PROJECT ALLOCATIONS",
        "cost": (4500, 6500, 9000), "published_price": "No public price; project planning allowance only",
        "order_url": "https://gomspace.com/product/nanocom-ax100/", "order_route": "Add to GomSpace quote and specify AX100-U sales part 200315 plus supported Mode 5 configuration.",
        "availability": "Current product page and 2024 PCN support U/UL sale, but exact delivery revision, lead time and firmware remain quote controlled.",
        "vendor_facts": ["UHF option covers 430–440 MHz; project planning frequency 437 MHz is conditional on authorization.", "Adjustable 24–30 dBm output; 0.1–38.4 kbps family capability.", "I²C, UART and CAN/CSP; 20-position hard-gold FSI connector; current page identifies MCX antenna connector.", "Operating temperature -30 °C to +85 °C; PCB/assembly claims are catalog statements."],
        "configuration": ["AX100-U sales part 200315; Mode 5 only per S11.", "Initial mission data rate 1200 bit/s with measured complete-modem threshold ≤-123 dBm at PER ≤1% for the selected frame.", "Powered from D1-IF branch B at 3.30 V nominal; signal pins high impedance when unpowered.", "Right-angle MCX implementation and 50 Ω coax to B09; final antenna tuned on assembled spacecraft."],
        "interfaces": ["H05 power", "H07 CAN/CSP", "H10 50 Ω RF/MCX", "GOSH/UART service"],
        "open": ["Written acceptance of full 3.3 V supply tolerance/transients and D1-IF protection", "Exact Mode 5 waveform, licensing frequency, occupied bandwidth and ground modem compatibility", "Measured sensitivity and transmitter performance for delivered revision", "RF connector orientation/envelope and mating coax", "Radiation/SEE, qualification/acceptance, software license and lead time"],
        "sources": ["S09", "S10", "S11", "procurement/BOM.csv", "engineering/02_Budgets_and_Analyses.md", "engineering/03_Interfaces.md"],
    },
    {
        "id": "B08", "slug": "GomSpace_NanoDock_DMC3", "vendor": "GomSpace", "item": "NanoDock DMC-3 carrier, top-side two modules", "qty": 1,
        "kind": "Named current COTS carrier; exact option configuration not selected", "mass": "51 g without daughterboards", "mass_basis": "S45 DS 1012962 rev 1.12, p14",
        "size": "91.9 × 88.7 × 8.6 mm", "size_basis": "S45, pp4 and 14; replaces incorrect CAD envelope assumption",
        "power": "Passive carrier in flight; the only active circuit is USB-to-serial and is powered from USB", "power_basis": "S45, pp6 and 14; daughterboard loads remain separate",
        "cost": (900, 1500, 2500), "published_price": "No current public price; project planning allowance only",
        "order_url": "https://gomspace.com/product/nanodock-dmc-3/", "order_route": "Current manufacturer page offers Add to quote and links its datasheet, 2025 option sheet and qualification certificate.",
        "availability": "Current public quote route verified 2026-09-15; stock, price and lead time remain unconfirmed.",
        "vendor_facts": ["Current product page describes support for four daughterboards and links the manufacturer documents.", "S45 identifies FSI, stack and breakout connectors and their pinouts.", "S46 is OSF 1012964 rev 2.3 dated 2025-04-14.", "S47 is qualification certificate 1028503 rev 1.0 and identifies product 200232."],
        "configuration": ["Carrier for two top-side modules: B06 A3200 and B07 AX100-U.", "Do not assume cross-vendor PC/104 pin compatibility to B02; route approved power/data through B10/B11.", "CAN bus must provide two endpoints and about 60 Ω unpowered bus resistance."],
        "interfaces": ["B06/B07 daughter-module connectors", "H04/H05 power routing", "H07 CAN routing", "Structure/standoff mounting"],
        "open": ["Exact option-sheet selection for connector population, supply routing and CAN termination", "Exact delivered revision, price, lead time and confirmation that certificate 1028503 applies", "Project mapping of A3200/AX100 positions and complete harness/stack pin review"],
        "sources": ["S07", "S12", "S13", "S44", "S45", "S46", "S47", "procurement/BOM.csv", "engineering/03_Interfaces.md", "drawings/freecad/CAD_SOURCE_TRACEABILITY.md"],
    },
    {
        "id": "B09", "slug": "ISISPACE_AntS_UHF_turnstile_5V", "vendor": "ISISPACE", "item": "AntS 1U–3U UHF turnstile, 5 V model", "qty": 1,
        "kind": "COTS deployable antenna requiring frequency/mechanical configuration", "mass": "<90 g", "mass_basis": "CURRENT VENDOR PAGE; project carries 90 g",
        "size": "98 × 98 × 7 mm stowed including supplied aluminum cover", "size_basis": "CURRENT VENDOR PAGE",
        "power": "<60 mW nominal for 5 V model; 2 W during deployment; maximum RF input 2 W", "power_basis": "CURRENT VENDOR PAGE",
        "cost": (1500, 2500, 4000), "published_price": "No public price; project planning allowance only",
        "order_url": "https://www.isispace.nl/product/vhf-uhf-antenna-for-1u-3u/", "order_route": "Select Turnstile and use ‘I want to buy’; specify UHF tuning and 5 V electronics.",
        "availability": "Current catalog product; exact turnstile frequency, element arrangement, connector and lead time require quote.",
        "vendor_facts": ["Up to four 55 cm tape-spring elements with redundant deployment system.", "Miniature 9-pin Omnetics electrical interface and I²C data.", "145–868 MHz family range; UHF main-beam gain 0 dBi and >50 MHz -10 dB bandwidth are catalog values.", "Operating -20 °C to +60 °C; deployment -5 °C to +60 °C; deployment under 5 s.", "Shipped-unit acceptance shown: functional and thermal cycling; not TVAC, vibration or shock."],
        "configuration": ["5 V UHF turnstile; final tuning on the complete spacecraft.", "Project commands deployment only at +5 to +45 °C and never while transmitting.", "Top accommodates B05 without obstructing stow or deployment.", "Separate isolated I²C branch and three-inhibit release/RF safety architecture."],
        "interfaces": ["H06 switched 5 V", "H09 isolated I²C", "H10 50 Ω RF", "B05 top-panel mount", "Structure and deployable keep-out"],
        "open": ["Authorized operating frequency and final tune requirement", "Exact RF connector/mating cable and full harness loss", "Signed B05/structure mounting arrangement and deployment envelope", "Release current/time trace and all-fault inhibit evidence", "Delivered-unit TVAC/vibration/shock scope, lead time and price"],
        "sources": ["S05", "procurement/BOM.csv", "engineering/01_Mission_and_Architecture.md", "engineering/03_Interfaces.md", "engineering/04_Mechanical_Thermal_Radiation.md"],
    },
    {
        "id": "B10", "slug": "D1IF_adapter", "vendor": "Integration vendor", "item": "D1-IF adapter: two 5 V to 3.3 V regulators, isolation and harness routing", "qty": 1,
        "kind": "Project-designed custom assembly using COTS candidate parts", "mass": "45 g", "mass_basis": "PROJECT ALLOCATION",
        "size": "88 × 88 × 6 mm CAD envelope", "size_basis": "ASSUMPTION; no schematic, layout or released PCB exists",
        "power": "Two independent 3.30 V branches: 1.0 A OBC design allocation and 1.2 A radio design allocation; project distribution efficiency 85% includes adapter losses", "power_basis": "PROJECT DESIGN ALLOCATION",
        "cost": (800, 1500, 3000), "published_price": "No product price; custom NRE/board/assembly/test planning allowance",
        "order_url": "Not applicable—release schematic/BOM/Gerbers and issue an RFQ to an integration/PCB assembly vendor. Candidate regulator reference: https://www.ti.com/product/TPSM82823", "order_route": "No purchase is authorized. First complete design and verification, then quote a flight assembly and engineering units.",
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

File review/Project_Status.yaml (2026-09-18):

project: DEGENERATE-1
schema_version: 0.1
updated: 2026-09-18
mission: Capture a recognizable photograph of Earth from orbit, downlink it, reconstruct it, and ultimately print it.
current_success_level: 0
current_success_label: Concept; partial evidence toward Engineering Model
ai_constraint:
  baseline: ChatGPT Plus, 20 USD/month, including Codex/Astra where available
  enterprise_ai_used: false
  specialist_ai_used: false
  paid_cloud_compute_used: false
  free_open_source_tool_preference: true
  paid_tool_boundary_requires_approval: true
cost_to_date:
  ai_usd: unknown
  software_tools_usd: 0
  spacecraft_hardware_eur: 0
  ground_station_eur: 0
  testing_verification_eur: 0
  regulatory_licensing_eur: 0
  launch_integration_eur: 0
  external_expert_review_eur: 0
  basis: No purchases, tests, filings, launch booking, or independent expert review are recorded in this package; confirm subscription history separately.
evidence_state:
  proposed: true
  calculated: true
  modeled: preliminary_FreeCAD_component_envelopes_with_unresolved_interferences
  simulated: hypothetical_parametric_sensitivity_only_not_component_specific_no_hardware_tested
  physically_built: false
  tested: false
  independently_expert_reviewed: false
  approved: false
  flown: false
  unknowns: many_critical_items
external_readiness_audit:
  framework: University of Hawaiʻi A Guide to CubeSat Mission and Bus Design, Edition 1
  audit_date: 2026-09-15
  matrix: review/Master_CubeSat_Readiness_Checklist.md
  total_items: 108
  complete: 3
  provisionally_addressed: 21
  in_progress: 38
  not_started: 30
  blocked: 16
  not_applicable: 0
  maturity_finding: Level 0 with partial evidence toward Level 1
  reassessment_basis: Public-information work is separated from final closure that requires a known downstream dependency; no new technical evidence was credited.
public_information_phase:
  status: active
  consumer_ai_baseline: ChatGPT Plus, 20 USD/month, including Codex/Astra where available
  software_baseline: free/open tools wherever reasonably practical
  provisional_mechanical_reference: EXOpod Nova public mechanical information
  direct_external_contact: downstream unless separately authorized and needed for an applicable release gate
  known_downstream_dependency_register: review/Known_Downstream_Dependencies.md
  readiness_rows_with_downstream_dependencies: 88
  public_requirements_deferred: false
  success_level_change: none
design_completion_standard:
  id: D1-DES-STD-001
  document: review/Theoretical_Buildability_Standard.md
  target: education_grade_theoretically_buildable_design
  purchase_required: false
  fabrication_required: false
  physical_testing_required: false
  exact_verifiable_parts_required: true
  custom_design_release_required: true
  reproducible_analysis_required: true
  tested_or_flightworthy_claim_permitted: false
architecture_trade:
  id: D1-TRD-ARCH-001
  document: engineering/12_Open_Bus_Architecture_Trade.md
  date: 2026-09-16
  selected_direction: BIRDS_derived_1U_with_project_released_custom_avionics
  architecture_frozen: true
  component_baseline_frozen: false
  rationale: strongest_public_whole_spacecraft_record_matching_1U_educational_imaging_mission
  rejected_unchanged:
    - mixed_ISISPACE_GomSpace_SkyFox_due_to_private_or_incomplete_interfaces
    - PyCubed_v05_due_to_documented_ATSAMD51_proton_sensitivity_and_unsafe_example_commands
  reference_only:
    - OreSat
    - VST104_Sierra
    - OpenLST
    - UPSat
  upstream_register: review/Open_Source_Upstream_Register.md
  flight_heritage_transferred_to_Degen1: false
detailed_design_baseline:
  control_register: Components/design_baseline/COMPLETENESS_MATRIX.md
  detailed_component_records: 12
  exact_selections_frozen:
    - Panasonic_BK120AAHU_3S2P_cells
    - SkyFox_piCAM_FM_default_60deg_IR_cut_infinity
    - Ebyte_E22_400M22S_UHF_module
    - AZUR_SPACE_81442_3G30A_Advanced_SCA_x10
    - Hirose_A3C_50pin_stack_pair
    - principal_EPS_semiconductors_and_deployment_switches
    - KJ_D84_magnet_and_Quetzal_geometry_HyMu80_rods
    - OreSat_derived_436_5_MHz_turnstile_and_Quetzal_derived_release_architecture
    - BIRDS4_derived_22_instance_1U_frame_geometry_and_6061T6_material
    - D1_FAB_001_SDS002RULC_dual_RBF_seven_stage_inhibit_and_JST_service_interface
    - D1_HAR_001_Spec55_JST_PA_PicoBlade_and_100mm_UFL_harness_architecture
    - YAGEO_Nexensos_32208571_Pt1000_panel_RTD_x5
  records_still_open:
    - D1_MECH_HW_001
    - D1_THM_001
    - D1_FSW_001
    - ground_segment_chain
  custom_records_requiring_release_and_verification:
    - D1_ADCS_001_passive_magnetic_assembly
    - D1_ANT_001_UHF_antenna_and_deployment_assembly
    - D1_STR_001_1U_rail_frame_and_load_structure
    - D1_FAB_001_launch_inhibit_RBF_and_front_access_assembly
    - D1_HAR_001_flight_and_service_harness_set
  theoretical_design_complete: false
  hardware_purchased_required_for_completion: false
next_step_proposal:
  id: D1-GATE-001
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

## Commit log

2026-09-14 Initialize DEGENERATE-1 project record
    [BOM.csv, D1_Envelope.scad, Program_Cost.csv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]
2026-09-14 Model documented Degen-1 accommodation in FreeCAD and record fit conflicts
    [Degen1_CAD001.FCStd, Degen1_CAD001_envelopes.step]
2026-09-14 Record log verification and preserve exact CAD final response
2026-09-15 Audit existing spacecraft components and procurement gaps
    [component_audit.csv]
2026-09-15 Add external CubeSat readiness audit
    [Master_CubeSat_Readiness_Checklist.csv]
2026-09-15 Add launch and deployer constraint gate
    [Launch_Deployer_Trade.csv, Master_CubeSat_Readiness_Checklist.csv, Requirements.csv]
2026-09-15 Reassess public-information readiness
    [Master_CubeSat_Readiness_Checklist.csv]
2026-09-15 Add transient thermal power model
    [Master_CubeSat_Readiness_Checklist.csv, Project_Cost_Ledger.csv, Requirements.csv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]
2026-09-15 Record Thermal Model Incident and Phase 1 evidence audit
    [BOM.csv, LOCAL_ARCHIVE_MANIFEST.csv, Master_CubeSat_Readiness_Checklist.csv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]
2026-09-15 Make component evidence closure the first engineering gate
    [Requirements.csv]
2026-09-15 Propose complete spacecraft operating component set
    [Proposed_Operating_Component_Set.csv]
2026-09-16 Select open 1U detailed design baseline
    [LOCAL_ARCHIVE_MANIFEST.csv]
2026-09-16 Select flight-referenced passive magnetic ADCS
    [LOCAL_ARCHIVE_MANIFEST.csv]
2026-09-16 Select custom UHF antenna and deployment architecture
    [LOCAL_ARCHIVE_MANIFEST.csv, PT-MIS-PCB-004_v1_BOM_Reference.xlsx]
2026-09-17 Select BIRDS-derived 1U structure baseline
    [B4_EM_frame6X v14.step, B4_frame1 v6.step, B4_frame1F v12.step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]
2026-09-17 Select launch inhibit and flight access architecture
    [BIRDS3-4_FAB_BOM.xlsx, LOCAL_ARCHIVE_MANIFEST.csv]
2026-09-17 Select flight harness architecture
    [LOCAL_ARCHIVE_MANIFEST.csv, harness_schedule.csv]
2026-09-18 Resume engineering and correct radio interface evidence
    [Project_Status.yaml]
2026-09-18 Focus physical spacecraft and reconcile radio carrier pin interface
